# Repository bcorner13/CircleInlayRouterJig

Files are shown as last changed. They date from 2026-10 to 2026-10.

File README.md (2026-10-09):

# CircleInlayRouterJig

Parametric, 3D-printed router template for cutting a circular inlay recess with a
**top-bearing pattern bit**. It's sized to fit a **laser-cut** inlay disc. Built in FreeCAD 1.1.

The bit's bearing rides the template's hole wall, and the cutter below it cuts the recess.
An underside relief keeps the cutter off the plastic, so only the bearing touches the
template. Set the disc diameter and thickness plus your bit's measurements, and the
template is derived automatically:

```
Recess        = InlayDiameter − LaserKerf + 2·InlayFitClearance
TemplateHole  = Recess + BearingOD − CutterDiameter
TemplateThick = CutterLength − RecessDepth + BearingStackHeight − CollarGap
```

Sizes planned: Ø100, Ø150, Ø200 (single piece on a 350 mm bed), for 3.1–3.2 mm thick discs. Ø250 is on the backlog.

## Status

Plan rev 2 approved, and the model was built 2026-10-08 (Ø150 default; audit clean; flex-tested at Ø100/150/200). Not yet test-printed.

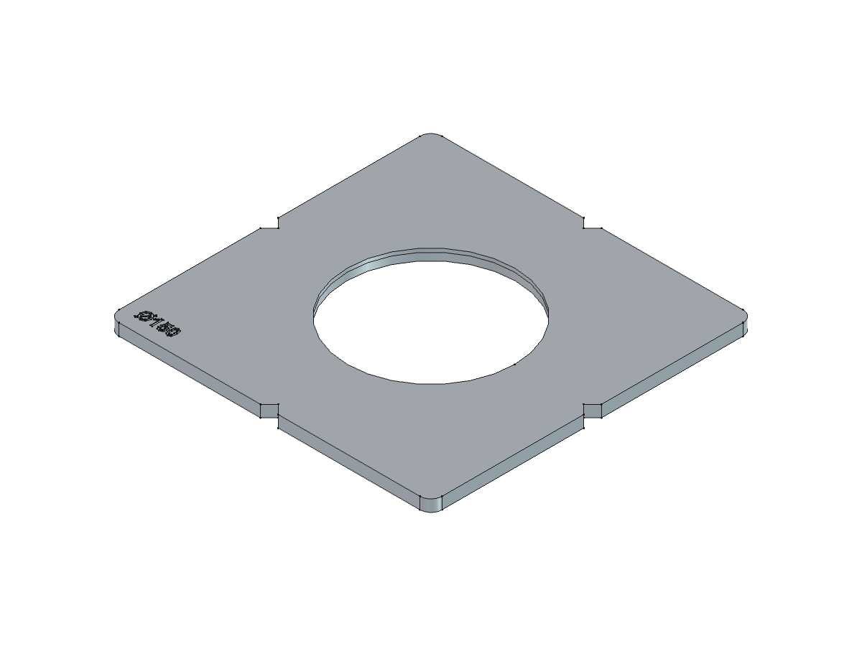
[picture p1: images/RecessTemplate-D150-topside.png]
Top side


## Layout

| Path | Contents |
|---|---|
| `Params.FCStd` | VarSet holding every parametric variable (created by `macros/00-bootstrap_params.FCMacro`) |
| `CircleInlayRouterJig.FCStd` | The template model |
| `intent.md` / `plan.md` | Design goal / approved modeling plan |
| `macros/` | FreeCAD macros that make all model changes |
| `scripts/audit_parametric.py` | Parametric-integrity audit; run it before every commit |
| `stl/`, `3mf/` | Print deliverables |
| `gcode/` | Slicer output (gitignored) |
| `images/` | Photos and renders |

## Usage

1. Measure your bit (cutter Ø and length, bearing Ø, bearing stack height) and your disc
   (diameter, thickness). Enter them in `Params.FCStd`.
2. Recompute `CircleInlayRouterJig.FCStd` and export `RecessTemplate`.
3. Run `macros/03-export_print_files.FCMacro` to write `stl/` and `3mf/` for every size. Print them
   **as exported, with the workpiece face on the bed** (don't flip), in PETG-rCF or similar, with
   ≥ 4 walls and ironing on top surfaces.
   Check the hole with calipers and tune `TemplateHolePrintComp` if needed.
4. Tape the template to the workpiece, aligning the edge notches to your layout lines.
5. Set the bit depth to the disc thickness and rout in **one full-depth pass**, keeping the
   bearing against the wall. A shallower pass would cut into the template.

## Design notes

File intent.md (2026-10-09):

# Intent — CircleInlayRouterJig

> HUMAN INPUT. Captured 2026-10-08 from Bradley's answers in the bootstrap session.
> Edit freely — plan.md is derived from this file, not the other way round.

Goal:
Parametric router template for cutting a circular inlay recess with a top-bearing pattern bit.
The inlay disc itself is **laser cut**, so the jig only has to rout a recess
whose diameter matches a laser-cut disc of known nominal diameter.

Constraints:

* Must follow CAD_STANDARDS.md
* Used with a top-bearing pattern bit (the bearing rides the template wall; no guide bushing).
  Changed from a guide bushing on 2026-10-08.
* Recess size must be derivable from the inlay diameter + bit geometry + laser kerf,
  so one knob (inlay diameter) re-sizes the template
* Printable without supports
* Material: PA6-CF12 or Polymaker Fiberon PETG-rCF08 (production material for test prints too)
* Target inlay diameters: **100, 150, 200 mm** (confirmed 2026-10-08); 150 mm is the first build.
  250 mm is on the backlog (too big for the bed in one piece)
* Disc thickness 3.1–3.2 mm; laser kerf negligible (< .0007 in = 0.018 mm)
* Router: **Milwaukee M18 FUEL compact router (2723-20)**, 5-3/4" sub-base
* Bit: top-bearing downcut flush-trim, 3/8" cutter × 3/8" cutting length, 1/4" shank
  (Jiiolioa, Amazon). Exact dims to be measured on arrival

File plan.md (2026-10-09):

# Plan — CircleInlayRouterJig

**Status: rev 2 (bearing-bit method), APPROVED by Bradley 2026-10-08.**

Rev 2, 2026-10-08: switched from a guide bushing to a **top-bearing pattern bit** (Bradley's
decision). Rev 1 (bushing kit) is in git history.

## Reference

`images/reference-IMG_0491.jpg`: the inlay is a laser-cut, laser-engraved wooden disc (a St. Benedict
medal, light plywood/basswood). It's engraved before inlaying, so the disc's cut edge is the only fit surface.
Discs are **3.1–3.2 mm** thick, and their laser kerf is negligible (< .0007 in = 0.018 mm). Size set: **Ø100 / 150 / 200**, with Ø150 first.
Ø250 is on the **backlog** (see the end of this plan).

## Tooling

* **Router**: Milwaukee M18 FUEL compact router 2723-20 with its 5-3/4" (146.05 mm) round sub-base.
  No guide bushing is used.
* **Bit**: Jiiolioa top-bearing downcut flush-trim bit (Amazon listing): 3/8" cutter Ø, 3/8" cutting
  length, 1/4" shank, 2-1/8" overall. Above the cutter, in order: **two stacked bearings**, then a
  **lock collar with a set screw**. The bearing stack height isn't published (~5.2 mm scaled from the
  listing drawing, which is an estimate). **Measure all bit dims with calipers on arrival.**

## Concept

A printed plate with a circular through-hole. The bit's **bearing rides the hole wall**, and the cutter,
directly below the bearing, cuts the workpiece. The recess wall lands on the bearing's path.

Cross-section of the plate (workpiece at the bottom, z = 0 on the workpiece surface):

```
  z = TemplateThick ─┐   ← router base rides here; lock collar must stay ABOVE this line
                     │ bearing contact band (BearingBand)
  z = ReliefHeight  ─┤
                     │ underside relief: Ø ReliefDiameter, cutter spins here without touching plastic
  z = 0 ─────────────┘   ← workpiece surface; cutter goes RecessDepth below it
```

Vertical stack, with the bit plunged to full depth (cutter tip at −RecessDepth):

```
cutter:   −RecessDepth … CutterLength − RecessDepth
bearings: CutterLength − RecessDepth … CutterLength − RecessDepth + BearingStackHeight
collar:   above the bearings, so the plate's top face must stay below it
```

Diameters:

```
recess must be:  RecessDiameter       = InlayDiameter − LaserKerf + 2·InlayFitClearance
bit cuts at:     RecessDiameter       = TemplateHoleDiameter − BearingOD + CutterDiameter
therefore:       TemplateHoleDiameter = RecessDiameter + BearingOD − CutterDiameter
model hole:      TemplateHoleModelD   = TemplateHoleDiameter + 2·TemplateHolePrintComp
relief:          ReliefDiameter       = TemplateHoleDiameter + 2·ReliefClearance
```

`BearingOD − CutterDiameter` is nominally 0. It's kept explicit because a cheap bit's bearing
and cutter can differ by ~0.1 mm, which matters at this fit.

Heights:

```
ReliefHeight  = CutterLength − RecessDepth + ReliefGap                       (cutter top + gap)
TemplateThick = CutterLength − RecessDepth + BearingStackHeight − CollarGap  (top of bearings − gap)
BearingBand   = TemplateThick − ReliefHeight = BearingStackHeight − ReliefGap − CollarGap
```

The bearing band is independent of disc thickness: ~3.2 mm with the estimated stack.

Router-base support, with the bearing on the wall: the base center sits at `(Hole − BearingOD)/2`
from the template center. Its outer edge must stay on the plate:

```
TemplateMargin = RouterBaseDiameter/2 − BearingOD/2 + BaseSupportOverlap
TemplateSide   = TemplateHoleDiameter + 2·TemplateMargin
```

## PARAMETERS

All live in `Params.FCStd` → `VarSet`, created by `macros/00-bootstrap_params.FCMacro`.
**TBD** = placeholder until measured or confirmed.

| Name | Type | Default | Group | Meaning |
|---|---|---|---|---|
| `InlayDiameter` | Length | 150 mm | Inlay | Nominal laser-cut disc diameter (the size knob) |
| `LaserKerf` | Length | 0 mm | Inlay | Diameter the disc loses to laser kerf. Measured < .0007 in (0.018 mm), so negligible; the knob is kept for other lasers/materials |
| `RecessDepth` | Length | 3.2 mm | Inlay | Routed depth = the **thickest** disc (range 3.1–3.2), because the engraved discs can't be sanded flush, so they sit flush to 0.1 below. Drives plate height |
| `CutterDiameter` | Length | 9.525 mm **TBD** | Tooling | Measured cutter Ø (3/8") |
| `CutterLength` | Length | 9.525 mm **TBD** | Tooling | Measured cutting length (3/8") |
| `BearingOD` | Length | 9.525 mm **TBD** | Tooling | Measured bearing Ø |
| `BearingStackHeight` | Length | 5.2 mm **TBD** | Tooling | Both bearings together; an estimate from the drawing |
| `RouterBaseDiameter` | Length | 146.05 mm | Tooling | Milwaukee 2723-20 sub-base, 5-3/4" (sourced; measure to confirm) |
| `InlayFitClearance` | Length | 0.05 mm | Clearance | Per-side glue gap, disc ↔ recess wall |
| `TemplateHolePrintComp` | Length | 0.15 mm | Clearance | Per-side FDM "holes print small" offset. **Per material**, so tune after the test print |
| `ReliefClearance` | Length | 1.0 mm | Clearance | Per-side radial gap, cutter ↔ relief wall |
| `ReliefGap` | Length | 1.0 mm | Template | Vertical gap, cutter top ↔ relief ceiling |
| `CollarGap` | Length | 1.0 mm | Template | Vertical gap, plate top ↔ lock-collar bottom |
| `BaseSupportOverlap` | Length | 2 mm | Template | Plate beyond the router base's outer edge |
| `AlignNotchWidth` | Length | 16 mm | Template | V alignment notch: mouth width at the plate edge (16 × 8 deep = 90° V) |
| `AlignNotchDepth` | Length | 8 mm | Template | V alignment notch: edge-to-apex depth (Bradley, 2026-10-08) |
| `StandoffHeight` | Length | 0 mm (off) | Standoff | Optional ring foot: raises the underside outside the ring so a low lip can pass under the margin. 0 = feature suppressed |
| `FootRingWidth` | Length | 15 mm | Standoff | Radial width of the ring foot around the relief |
| `FootRingDiameter` | Length | *derived* | Derived | `ReliefDiameter + 2·FootRingWidth` (182.1 at Ø150) |
| `PlateCornerRadius` | Length | 10 mm | Template | Fillet on the plate's 4 outer corners: less corner lift when printing, no sharp corners |
| `RecessDiameter` | Length | *derived* | Derived | see Concept |
| `TemplateHoleDiameter` | Length | *derived* | Derived | see Concept |
| `TemplateHoleModelD` | Length | *derived* | Derived | Hole as modeled (includes print comp) |
| `ReliefDiameter` | Length | *derived* | Derived | see Concept |
| `ReliefHeight` | Length | *derived* | Derived | see Concept |
| `TemplateThick` | Length | *derived* | Derived | see Concept |
| `BearingBand` | Length | *derived* | Derived | Wall height the bearing actually rides (validation only; drives nothing) |
| `TemplateMargin` | Length | *derived* | Derived | see Concept |
| `TemplateSide` | Length | *derived* | Derived | see Concept |

Each concern gets its own knob: glue fit (`InlayFitClearance`), laser process (`LaserKerf`), FDM hole size
(`TemplateHolePrintComp`), cutter-to-plastic clearance (`ReliefClearance`, `ReliefGap`), and collar clearance
(`CollarGap`). Rev 1's `LeadInChamfer` is **dropped**. Any chamfer on the hole would eat into the
~3 mm bearing band, and the bit enters from above anyway.

Worked example (Ø150; bit dims are listing/placeholder values): Recess **150.10**; Hole **150.10**; modeled
hole **150.40**; relief **Ø152.10 × 7.325** high; plate **290.63 × 290.63 × 10.525**; bearing band **3.2**; margin **70.26**.

Depth tolerance: `ReliefGap` and `CollarGap` (1 mm each) absorb router depth-setting error of up to ~±0.9 mm
before the cutter touches the relief ceiling or the collar touches the plate top.

## FEATURE TREE

`CircleInlayRouterJig.FCStd`, Body `RecessTemplate`. The plate's bottom face (workpiece side) is at z = 0,
centered on X/Y:

1. `DatumPlane_Base`: PartDesign::Plane on Origin XY (offset 0)
2. `Sk_Plate` on `DatumPlane_Base`: square, side `TemplateSide`, symmetric about the origin, with corners rounded **in the sketch**
   (tangent arcs, radius `PlateCornerRadius`). That avoids a PartDesign Fillet, which selects edges by index
3. `Pad_Plate`: Length = `TemplateThick` (+Z)
4. `Sk_Hole` on `DatumPlane_Base`: circle Ø `TemplateHoleModelD` at the origin
5. `Pocket_Hole`: ThroughAll
6. `Sk_Relief` on `DatumPlane_Base`: circle Ø `ReliefDiameter` at the origin
7. `Pocket_Relief`: Length = `ReliefHeight`, cutting up from the bottom face
7b. `Sk_Standoff` (circle `FootRingDiameter` + circle `2·TemplateSide`) / `Pocket_Standoff`: Length = `StandoffHeight`,
   `Suppressed` = `StandoffHeight == 0mm` (optional ring foot, see OPTION section)
8. `Sk_Notch` on `DatumPlane_Base`: one **V notch** (90°, apex on the X axis `AlignNotchDepth` inside the +X edge, mouth
   `AlignNotchWidth` wide at the edge), polar-patterned ×4 onto the edge midpoints
9. `Pocket_Notches`: ThroughAll
10. `DatumPlane_Top`: offset `TemplateThick`. Created only if a top-face label is approved (Open Q 6)

No sketch attaches to a feature face.

**Print orientation: as modeled, with the WORKPIECE (bottom) FACE ON THE BED.** Revised 2026-10-08 at export time.
Rev 2 originally said top face down; that was reversed because:
* **Strength:** flat is strongest either way. Layers run parallel to the plate, and the bearing's side load is
  carried along continuous perimeters. Printing on edge would put layer lines across the load, and it wouldn't fit the bed.
* **Fit accuracy (decisive):** bottom-down keeps the bearing band at z = ReliefHeight to TemplateThick (7.3–10.5), in the upper
  layers and away from first-layer elephant foot. Top-down would put the fit-critical surface on the squished first layers.
* **Label:** engraved into the top layers, so it prints crisp. Top-down would have turned its floor into 0.6 mm-high bridges.
* **Only overhang:** the relief ledge, `(ReliefDiameter − TemplateHoleModelD)/2` = 0.85 mm, about two extrusion widths. It
  prints without supports, and nothing touches it.
* **Surfaces:** the workpiece face is bed-flat (good for tape and for sitting flat). The router glides on the top layers. Ironing
  was planned but is **off**: on D150 it took 4h04m of an 8h45m print for a cosmetic gain (2026-10-09).

`macros/03-export_print_files.FCMacro` exports in this orientation and asserts it (ZMin = 0, centered on X/Y). Don't flip it in the slicer.

**Slicer notes for strength and fit:** use enough walls that the 3.2 mm bearing band is all perimeters (≥ 4 at a 0.4 mm
line width), with ≥ 5 top layers. The hole wall's Z-seam leaves a bump the bearing rides over, so use a scarf seam if
the slicer has one, or aligned seams (not random). *(Unverified for Creality Print; check its seam options.)*

## CONSTRAINT STRATEGY

* Every sketch is fully constrained to the origin/axes using Symmetric + Horizontal/Vertical constraints. Every
  dimension is `setExpression`-bound to `<<Params>>#VarSet.<Name>`. Feature Lengths bind the same way.
* Sketches and features bind to the **derived** names, so each formula lives once, in the VarSet.
* Built with typed MCP tools (`create_sketch`, `add_sketch_*`, `sketcher_add_constraint_*`, `pad_sketch`,
  `pocket_sketch`, `create_datum_plane`) and recorded as `macros/NN-*.FCMacro`.

## VALIDATION

1. `python3 scripts/audit_parametric.py` is clean.
2. **Flex tests** (a binding alone isn't proof the Param drives geometry):
   - `InlayDiameter` 150 → 100: the measured hole edge radius = `TemplateHoleModelD/2`, and the plate bbox = `TemplateSide`.
   - `RecessDepth` 3.2 → 4.2: the plate gets 1 mm thinner and the relief 1 mm shorter; the bearing band stays the same.
   Restore the values afterwards.
3. `validate_object` / `part_check_shape`: a valid closed solid, centered on X/Y.
4. Geometry asserts: `TemplateSide ≤ 350` (K2 Plus bed); `BearingBand ≥ 2.5`; `ReliefHeight < TemplateThick`.
5. **Bench checks before the first rout:**
   - Measure the bit (cutter Ø/length, bearing Ø, bearing stack height) and update the Params.
   - Collet check: with the bit set ~`TemplateThick + RecessDepth` (~13.7 mm) below the base, confirm
     ≥ 3/4" of shank is in the collet and the collet nut clears the lock collar.
6. **Physical:** print **Ø100** first, in the production material, bottom (workpiece) face on the bed, using `stl/RecessTemplate-D100.stl`. Measure the
   bearing band Ø on two axes. Set the slicer's XY shrink from the scale error, then `TemplateHolePrintComp`
   from any remaining constant offset. Check the plate's flatness. Rout scrap in **one full-depth pass**
   and dry-fit a laser-cut disc. Tune `InlayFitClearance` / `LaserKerf`.

## USAGE CONSTRAINT: ONE FULL-DEPTH PASS

The plate's height is computed for the cutter at full `RecessDepth`. On a shallower pass the cutter sits
higher and **cuts into the plate above the relief**. For the 3.1–3.2 mm plywood discs, a 3/8" downcut at full
depth is a normal single pass for a compact router. If multiple passes are ever needed, raise `ReliefGap`
by the shallowest pass's shortfall. That shrinks `BearingBand`, so check the ≥ 2.5 mm assert.

## MATERIAL

Candidates: **PA6-CF12** (brand TBD) or **Polymaker Fiberon PETG-rCF08**. **PETG-rCF08 is recommended**,
because PA6 absorbs moisture and swells, so a nylon hole drifts with shop humidity.

* Shrink is a percentage and scales with size: ~0.5 mm diametral on a 200 mm hole at 0.25%. **Compensate
  it in the slicer's per-filament XY shrinkage**, not in CAD. One true-size STL then serves both materials.
  *(Assumes Creality Print/Orca has a per-filament shrinkage setting. Verify it.)*
* CF filament is abrasive, so it needs a **hardened nozzle**. Dry before printing (PETG-rCF08: 65 °C / 3 h, per the Polymaker TDS).
* Flatness matters, since warp tilts the router. Print in the enclosed chamber and check with a straightedge.
* The bearings ride on printed CF-PETG; expect slow wear of the bearing band over many uses.

## OPTION: STANDOFF RING FOOT (furniture with a low lip), added 2026-10-08

For pieces where a lip would sit **under** the template, e.g. edge molding (Bradley's example: a bamboo bed
tray with a guardrail rim). `StandoffHeight > 0` un-suppresses `Pocket_Standoff`, which removes `StandoffHeight` from the
underside everywhere outside a **ring foot** of diameter `FootRingDiameter` around the relief:

* The ring always lands on the flat field around the inlay. The router's center (~73 mm from center at Ø150) stays inside
  the ring (~91 mm), so it's stable. A lip may pass under the raised margin if it is **lower than `StandoffHeight`** and
  **farther than `FootRingDiameter/2` from the inlay center**.
* The bearing band is measured from the wood, so it **doesn't move**, and the bit setup stays the same.
* **Limit:** the plate web `TemplateThick − StandoffHeight` must be ≥ 4 mm (asserted by macro 03), so `StandoffHeight` ≤ ~6.5 mm with
  the current bit. Taller lips need a bit with a longer cutting length (raise `CutterLength`).
* **Print orientation flips:** with feet, macro 03 exports **top face down**, because bottom-down would leave the whole margin as an
  overhang. Files are tagged `-S<height>`, and **elephant-foot compensation is required**, since the bearing band is then on the first layers.
* Often unnecessary: if the field inside a rim is at least as large as the plate, the template just sits on the field.
  Measure first.
* **Fibogollo bamboo bed tray (40 × 30 cm, 40 mm rim, Bradley confirmed 2026-10-08): feet do NOT apply.** The rim is far
  above the ~6.5 mm limit, so the template must sit on the floor inside the rim. There the binding constraint is that the
  **router base's sweep** (diameter `TemplateHoleDiameter − BearingOD + RouterBaseDiameter`) must clear the rim, because
  the base rides ~10.5 mm above the floor, below the rim top. With the 146 mm template base on an estimated ~275 mm inner
  short side: Ø100 fits (sweep 236.6), Ø150 does not (286.6). A smaller base (the bearing bit doesn't need the bushing
  base; a forum reports the 2723 also ships with a ~4" base) would shrink the Ø150 sweep to ~242 mm. That's just a
  `RouterBaseDiameter` change. Still needed: the inner floor dimensions, the floor thickness, and the other base's diameter.

Verified: suppressed at 0 (volume unchanged); at 5 mm it removed exactly (plate outline − ring) × 5; bearing band unchanged;
the flipped export read back with the band at the bed and only the ring above the standoff.

## SIZE SET & BED FIT

Every size comes from one model by changing `InlayDiameter`. `macros/NN-export_all_sizes.FCMacro` will loop
through **100, 150, 200**, recompute, export `stl/RecessTemplate-D<size>.stl`, and restore the original value.

K2 Plus 350 mm bed (margin 70.26, hole = disc + 0.10):

| Disc | Plate side | Fit |
|---|---|---|
| 100 | 240.63 | ✅ 109 mm spare |
| 150 | 290.63 | ✅ 59 mm spare |
| 200 | 340.63 | ✅ 9.4 mm spare. Confirm the real printable area |

## BEFORE FIRST ROUT (not approval blockers; the Params absorb them)

* **Measure the bit** on arrival: cutter Ø, cutting length, bearing Ø, bearing stack height (5.2 mm is an
  estimate from the listing drawing). Update the Params and re-run the asserts. Do the collet check (Validation 5).

## DECISIONS (approved 2026-10-08 with the plan)

1. **Workholding: double-sided tape only.** No holes in the plate.
2. **Size label: yes.** A shallow engraved label (e.g. "Ø150") on the top face, in a **corner**. The corners
   lie outside the router base's sweep (base reach ≈ Hole/2 + TemplateMargin − BaseSupportOverlap from center,
   which is less than the corner distance). New Params: `LabelSize`, `LabelDepth`, `LabelInset`. The text should
   derive from `InlayDiameter` if FreeCAD expressions allow it (verify live). Otherwise the export macro sets it per size.
3. **Plate outline: solid square.**
4. PA6-CF12 brand: open, but not blocking (PETG-rCF08 recommended).

## BACKLOG

* **Ø250 template** (deferred 2026-10-08). The plate would be ~390.6 mm, over the 350 mm bed. Options when it's
  picked up: (a) a **segmented plate**, 2 or 4 keyed pieces with `SegmentCount` and a joint-clearance Param, recommended;
  the bearing crosses the seams, so they must register flush. (b) A thinner margin, leaving the router base
  overhanging ~20 mm. (c) A narrow ring plus a separate sub-base.

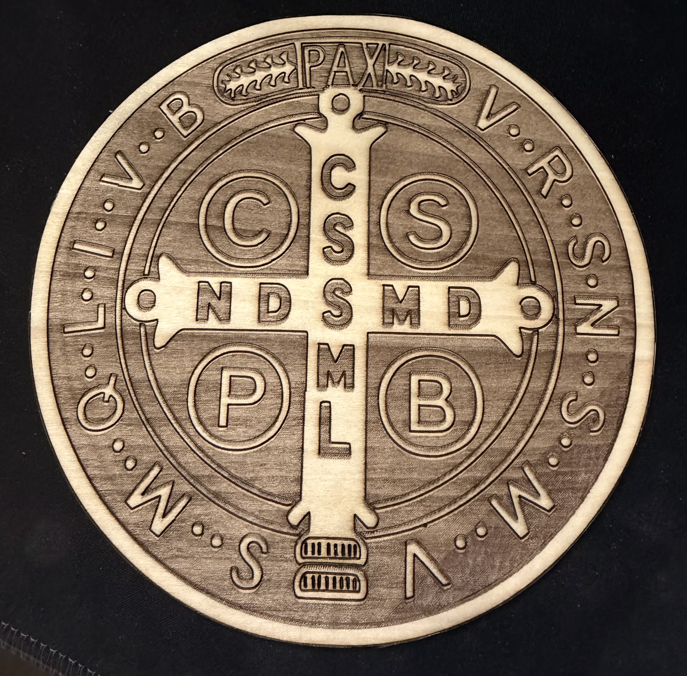
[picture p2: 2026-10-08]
images/reference-IMG_0491.jpg

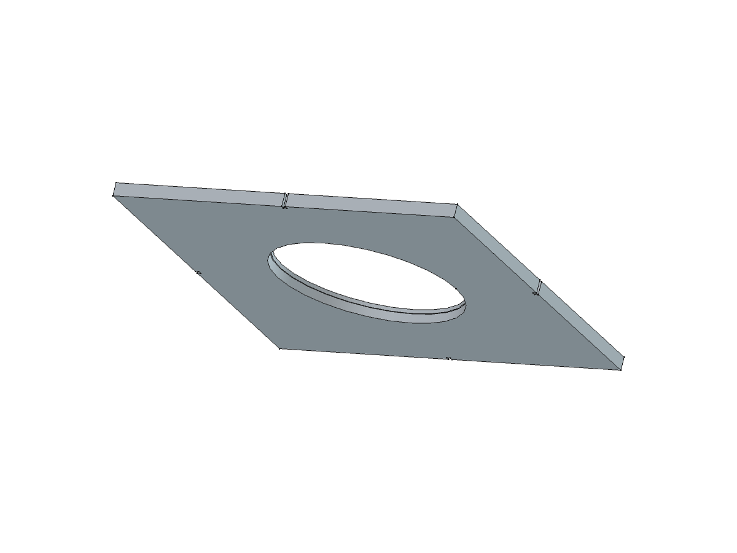
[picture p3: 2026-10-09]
images/RecessTemplate-D150-underside.png

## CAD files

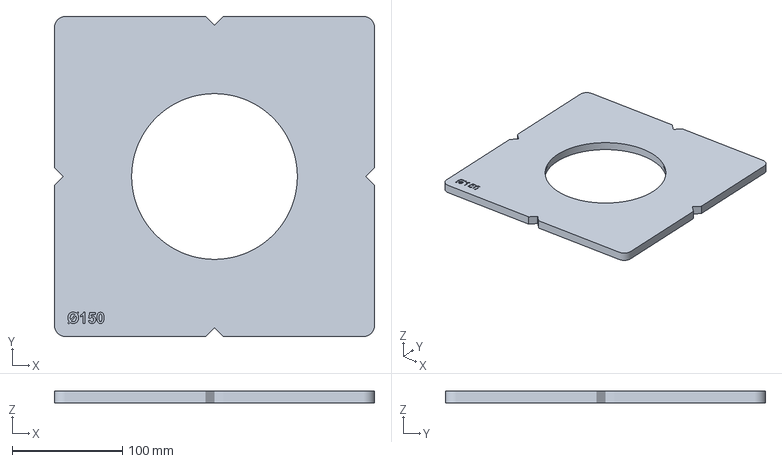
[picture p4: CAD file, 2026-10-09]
3mf/circleinlayjig-base.3mf
290.6 x 290.6 x 10.5 mm

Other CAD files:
Params.FCStd
CircleInlayRouterJig.FCStd

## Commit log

2026-10-08 Bootstrap CircleInlayRouterJig project scaffold
    Per PROJECT_BOOTSTRAP.md: standards copies, guard hook, audit script
    (Lockbox Bracket copy with all known enum fixes), filled CLAUDE.md,
    intent.md, draft plan.md (awaiting approval), Params bootstrap macro,
    reference photo of the laser-cut inlay disc.
2026-10-08 Set inlay diameter to 150 mm; widen TemplateMargin for router-base support
    Plate is now 312.65 mm square (fits K2 Plus bed). Margin of 75 mm is a
    placeholder pending the real router base diameter.
2026-10-08 plan: add Ø100–250 size set, bed-fit table, open question on oversize strategy
2026-10-08 Router = Milwaukee M18 FUEL 2723-20; derive TemplateMargin from base diameter
    Margin = base radius - bushing radius + overlap (67.09 mm) instead of the
    75 mm guess. Ø100/150/200 now fit the 350 mm bed (Ø200 with ~3 mm spare);
    Ø250 still exceeds it, so the strategy is an open question.
2026-10-08 plan: material section (PA6-CF12 / PETG-rCF08), slicer-side shrink compensation
2026-10-08 plan: note candidate inlay kit; measure bushing/collar/bit on arrival
2026-10-08 plan rev 2: switch to top-bearing pattern bit
    Bearing rides the template wall, so there's no bushing offset or concentricity error.
    Adds underside relief (cutter clearance) and derives plate thickness from
    RecessDepth + bit geometry, leaving a ~3.2 mm bearing band below the lock collar.
    Drops the bushing Params and LeadInChamfer. Plate sizes shrink:
    Ø100/150/200 = 240.5/290.5/340.5 mm; Ø250 = 390.5 (still over the bed).
    Usage constraint: one full-depth pass.
2026-10-08 Disc 3.1-3.2 mm (RecessDepth 3.2), kerf negligible, Ø250 to backlog
    Bit measurements become pre-rout checks, not approval blockers. Remaining
    open questions now carry proposed defaults.
2026-10-08 Record laser kerf units: < .0007 in (0.018 mm)
2026-10-08 Build RecessTemplate model (Params + macros 01/02)
    - Params.FCStd: 31-variable VarSet created by macro 00 (bearing-bit plan rev 2)
    - CircleInlayRouterJig.FCStd: plate, bearing-wall hole, underside relief,
    4 alignment notches, engraved corner size label derived from InlayDiameter
    - Macro 00: match this project's Params by file path, abort on a foreign Params
    (<<Params>> resolves by label); add Label params
    - Macro 01: save the empty model before binding (FreeCAD refuses cross-doc
    expressions from an unsaved owner); notch sketch no longer over-constrained
    - Verified: audit clean, single valid solid, volume = analytic, flex tests at
    Ø100/150/200 and RecessDepth 4.2 match Params, label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
    [CircleInlayRouterJig.FCStd, Params.FCStd]
2026-10-08 Add export macro 03; print bottom (workpiece) face down
    Exports stl/ + 3mf/ for Ø100/150/200 as modeled (ZMin=0, centered), with
    pre-flight asserts (bed fit, bearing band, single valid solid, label text).
    Meshes at 0.005 mm deflection and verifies the meshed hole loses <= 0.01 mm
    (the 0.1 mm default lost 0.036 mm on Ø200).
    Orientation revised from top-face-down: flat is strongest either way, and
    bottom-down keeps the fit-critical bearing band away from first-layer
    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
2026-10-08 V alignment notches (8 deep, 90 deg) and R10 rounded plate corners
    - Sk_Notch is now a V: apex on the centerline AlignNotchDepth inside the edge,
    mouth AlignNotchWidth wide at the edge (16 x 8 = 90 deg)
    - New PlateCornerRadius (10 mm): corners rounded as tangent arcs in Sk_Plate
    rather than a PartDesign Fillet (no edge-index selection)
    - Verified: sketches fully constrained, volume = analytic, apex/mouth measured,
    corner knob flexed 10->20->10, label intact; audit clean
    [CircleInlayRouterJig.FCStd, Params.FCStd]
2026-10-08 Optional standoff ring foot for furniture with a low lip
    - New StandoffHeight (0 = off) / FootRingWidth; derived FootRingDiameter
    - Pocket_Standoff raises the underside outside a ring foot around the relief;
    Suppressed is bound to StandoffHeight == 0mm, so the default model is unchanged
    - Export macro: with feet on, flips to top-face-down (bottom-down would be one
    big overhang), tags files -S<h>, asserts plate web >= 4 mm
    - Verified: suppressed volume unchanged; S5 removed exactly (outline - ring) x 5;
    bearing band unchanged; flipped export read back correct; audit clean
    [CircleInlayRouterJig.FCStd, Params.FCStd]
2026-10-08 plan: bed-tray case (40 mm rim) - feet don't apply; router-base sweep is the limit
2026-10-09 Export slicer-ready Creality projects with print settings
    CIRJ-03 now builds each 3mf/RecessTemplate-D<size>.3mf from the base
    Creality Print project (3mf/circleinlayjig-base.3mf: mouse ears, VLH
    50/7, elephant-foot comp), swapping in the 0.005 mm mesh and centering
    it on the bed. Overrides: 4 walls, 5 top layers, topmost ironing, no
    wipe tower; 4.5 mm ears for D200 (5 mm overflows the 350 bed). The VLH
    table is kept only if the plate height still matches; dropped for the
    flipped standoff variant. Each file is read back and verified.
    Creality Print 7.3 on macOS has no working CLI; verify in the GUI.
    [circleinlayjig-base.3mf]
2026-10-09 Save model and Params (saved by Bradley in FreeCAD 2026-10-09)
    [CircleInlayRouterJig.FCStd, Params.FCStd]
2026-10-09 Brim ear max angle 150 so ears find the R10 corners
    At 125 Creality generated no ears on the rounded-corner plate.
2026-10-09 Turn ironing off in the exported slicer projects
    Topmost ironing took 4h04m of an 8h45m D150 print for a cosmetic gain.
